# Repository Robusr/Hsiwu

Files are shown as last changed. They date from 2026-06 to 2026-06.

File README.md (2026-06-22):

<p align="center">
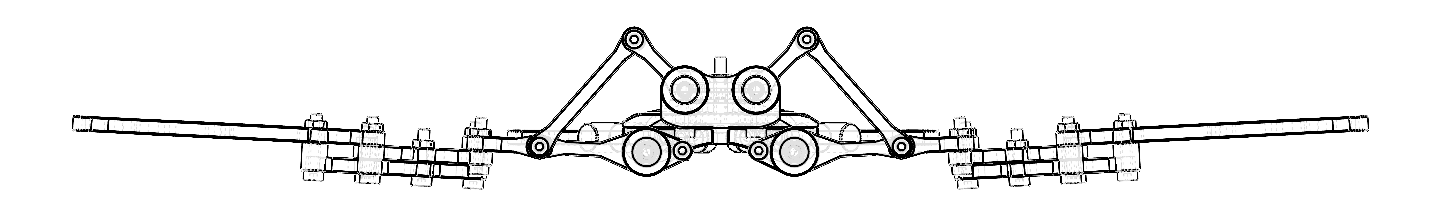
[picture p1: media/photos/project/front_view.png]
Hsiwu - Biomimetic Bat Robot Front Elevation
  
</p>

<h1 align="center">Hsiwu</h1>

<p align="center">
  <strong>MCU-less Analog Biomimetic Bat Flapping-Wing Robot</strong>
  <br>
  Three-segment independently-driven wings with pure analog control
</p>

<p align="center">
  
  
  
  
  
  <br>
  <a href="./README.md">English</a> | <a href="./README.zh-CN.md">中文版本</a>
</p>

---

## Name Origin

<p align="center">
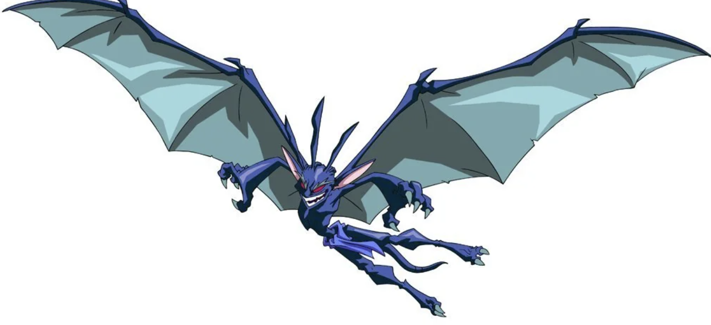
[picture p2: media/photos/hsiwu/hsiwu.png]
Hsi Wu — Sky Demon from Jackie Chan Adventures
  
  <br>
  <em><strong>Hsi Wu</strong> (西木 / Xī Mù), the Sky Demon of <strong>Jackie Chan Adventures</strong>.</em>
</p>

The project name **Hsiwu** is derived from **Hsi Wu** (西木), the bat-like **Sky Demon** from *Jackie Chan Adventures* (《成龙历险记》). A fitting namesake: just as Hsi Wu ruled the sky with his segmented, morphing wings, this robot replicates the segmented membrane deformation of a real bat in flight.

---

## About The Project

**Hsiwu** — named after the bat-like Sky Demon — is a biologically inspired bionic bat flapping-wing robot. Unlike conventional single-segment rigid-wing drones, it replicates the segmented membrane deformation of a real bat in flight. Each wing is divided into three independently driven segments — **leading edge**, **middle section**, and **trailing edge** — each powered by its own DC motor.

The bionic design takes the *Rhinolophus luctus* (great woolly horseshoe bat) as its morphological reference. Through a crank-rocker four-bar linkage mechanism, the continuous rotary motion of each DC motor is converted into the oscillating reciprocating swing that drives the wing segments—faithfully reproducing the coupled flapping-and-stretching kinematics of a real bat wing membrane.

A defining characteristic of this project is its **pure analog control architecture**. The system uses no microcontroller (MCU) and no embedded software whatsoever. Instead, it relies entirely on discrete analog and digital logic circuits — **NE555** timers, **74HC04** inverters, and **L293D** H-bridge drivers — to generate the synchronized periodic reciprocating motion that drives the wings.

The project spans a complete engineering stack: analog electronics design, digital logic, custom PCB layout, mechanical structure modeling (SolidWorks), FDM 3D printing, and hardware assembly and debugging.

> **Reference Paper**: The aerodynamic and mechanical principles are adapted from *"Design and Manufacture of Bionic Bat Aircraft"* (Qi Jinhao, Zhang Weiping, 2020), published in *Machine Design and Research*, Vol. 36, No. 5. The reference prototype achieves a 205 mm wingspan, 17.81 g total mass, 70° flapping angle, ~10 Hz flapping frequency, and ~0.16 N lift under a 3.7 V power supply.

<p align="center">
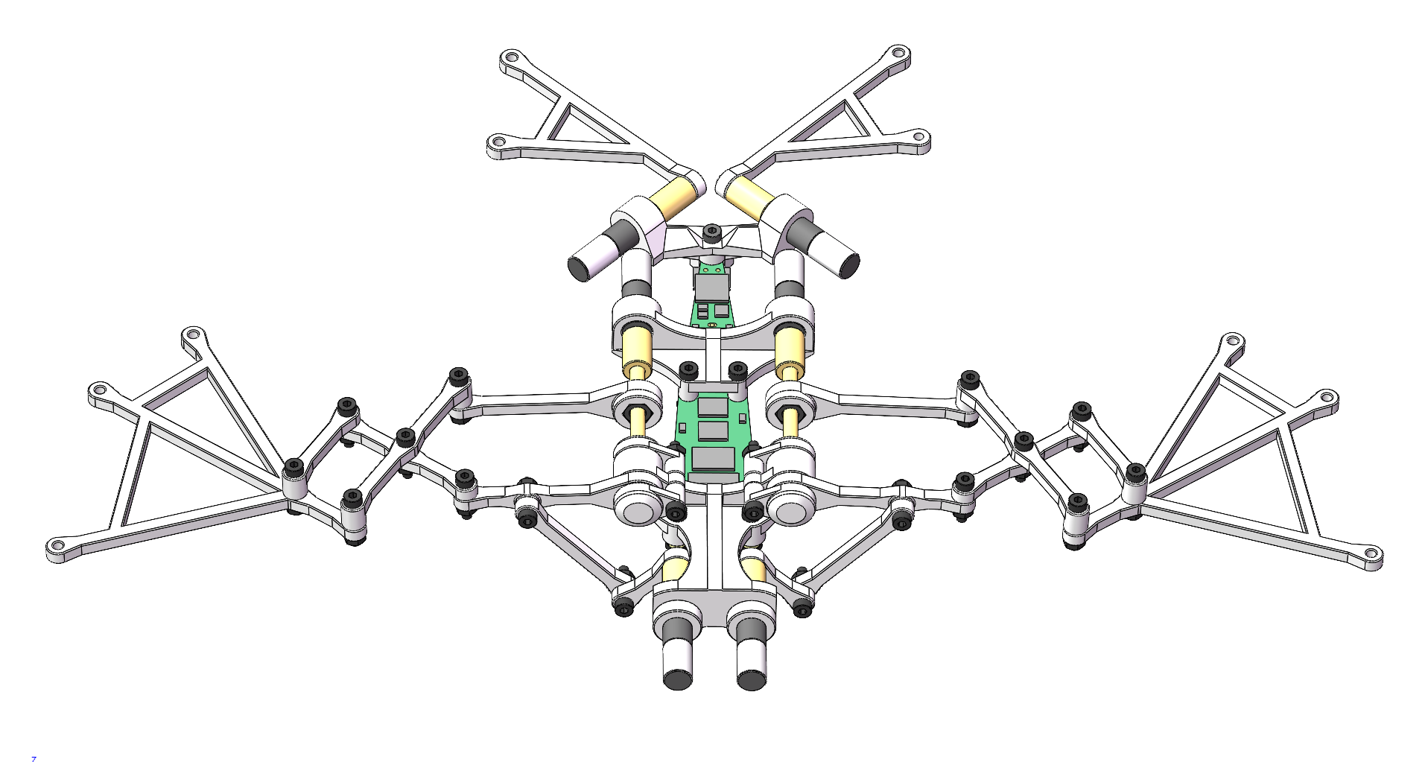
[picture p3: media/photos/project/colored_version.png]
Hsiwu Full Assembly Render
  
  <br>
  <em><strong>Figure 0 — Project Overview.</strong> Full-color 3D render of the complete Hsiwu assembly. The bilateral symmetric frame chassis (central support, head support, tail bracket), six independently-driven wing segments (three per side — leading, middle, trailing edges), linkage rods, lead-screw-driven scissor expansion mechanism, and custom-shaped PCB are all visible. This render corresponds to the final assembly state defined in <code>final_assembly.SLDASM</code>.</em>
</p>

---

## Key Features

- **Bio-inspired Wing Kinematics** — Three independently-driven segments per wing (Leading, Middle, Trailing), each with its own DC motor, mimicking the stretching and bending of a real bat's wing membrane. The crank-rocker four-bar linkage converts continuous motor rotation into oscillatory flapping.
- **Zero MCU / Zero Code** — Pure analog control: NE555 astable multivibrators for timing, 74HC04 hex inverters for phase splitting, and L293D dual H-bridges for bidirectional motor drive. No microcontroller, no firmware, no programming required.
- **Custom Shaped PCB** — A specialized irregularly-shaped PCB designed in EasyEDA (LCEDA) and Altium Designer, contour-fit to the internal mechanical frame. Integrates power management, signal generation, and motor driving onto a single compact board.
- **Modular Mechanical Design** — Fully parameterized 3D models built in SolidWorks. Frame components are FDM 3D-printable, assembled with standard M2/M3 screws and hinge linkages for easy tuning and repair.
- **Integrated Power Management** — Single-cell 3.7V LiPo battery input with MT3608 boost converter (3.7V → 7.35V for motors), on-board LDO regulation (5V for logic), reverse-polarity protection, and power switch with indicator LED.

---

## System Architecture

### 1. Electronics System (`/electronics`)

The core logic is distributed across five functional blocks integrated onto a single custom PCB:

<p align="center">
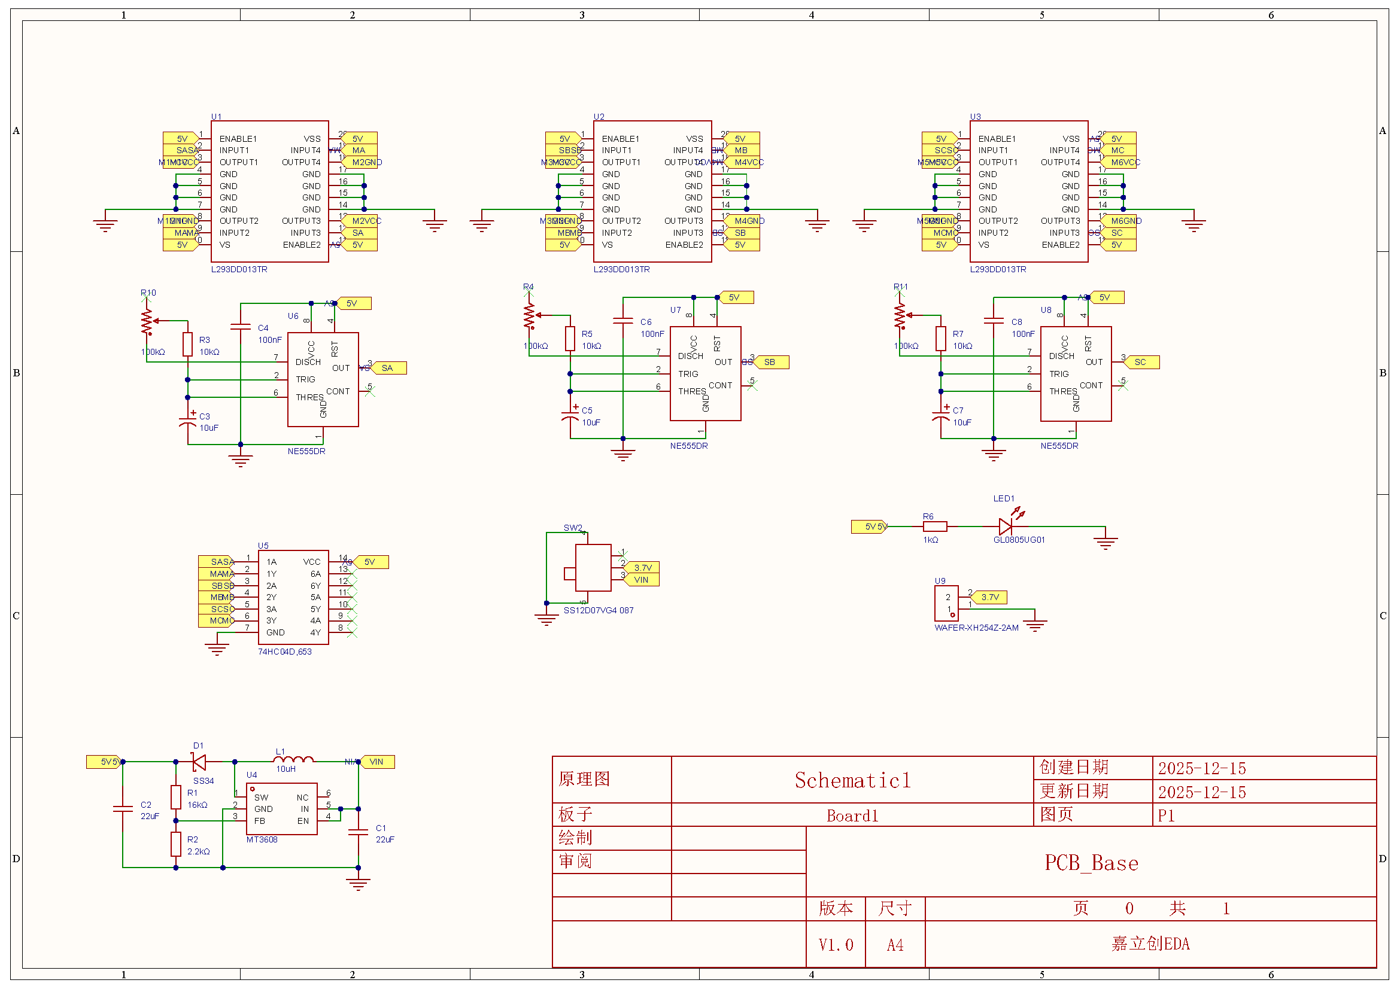
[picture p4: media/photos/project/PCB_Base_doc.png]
Full System Schematic
  
  <br>
  <em><strong>Figure 1 — Full System Schematic.</strong> Complete circuit diagram showing four functional blocks: (left) MT3608 boost converter with Schottky diode reverse-polarity protection and power switch; (upper-middle) three NE555 astable multivibrator stages generating independent ~4.8 Hz square-wave timing signals; (right) 74HC04 hex inverter for complementary phase generation; (lower) three L293D dual H-bridge drivers, each using one half-bridge channel per motor to produce continuous forward/reverse reciprocation.</em>
</p>

| Block | Components | Function |
|---|---|---|
| **Power Supply** | MT3608, LDO, Schottky diode | 3.7V LiPo → 7.35V (boost, motors) + 5V (LDO, logic). Reverse-polarity protection, on/off switch with indicator LED. |
| **Timing Generation** | 3× NE555 (astable) | Three independent, synchronized square-wave oscillators at ~4.8 Hz. Sets the flapping frequency. Each NE555's RC network can be independently tuned for per-segment timing adjustment. |
| **Phase Inversion** | 1× 74HC04 hex inverter | Inverts the three NE555 outputs to produce complementary logic levels for H-bridge direction control. Each NE555 output drives one inverter channel, yielding the inverted signal for the opposing half-bridge. |
| **Motor Drive** | 3× L293D dual H-bridge | Each L293D uses one half-bridge channel per motor. Complementary logic signals produce continuous forward/reverse reciprocation. Built-in flyback diodes protect against inductive kickback. |
| **PCB Layout** | Custom contour | Vertical modular layout; board outline shaped to fit the internal mechanical frame. Irregular board profile matches the central support chassis curvature. |

<p align="center">
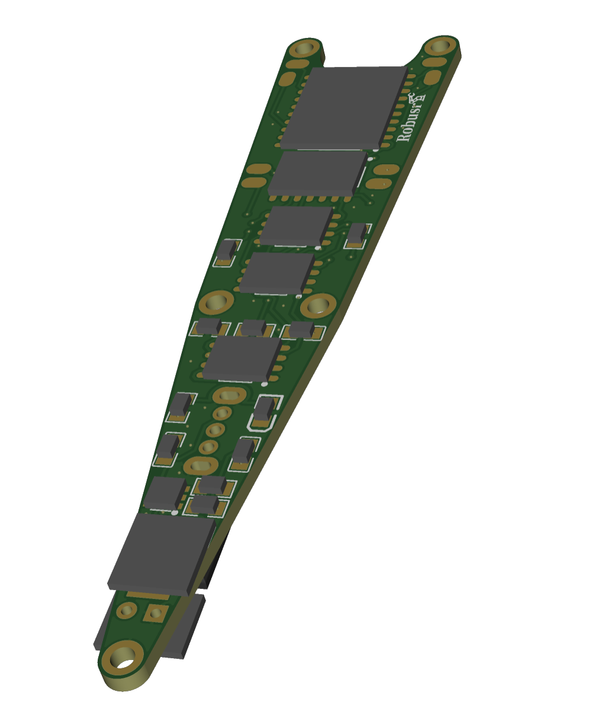
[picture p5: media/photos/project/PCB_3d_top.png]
3D PCB Render
  
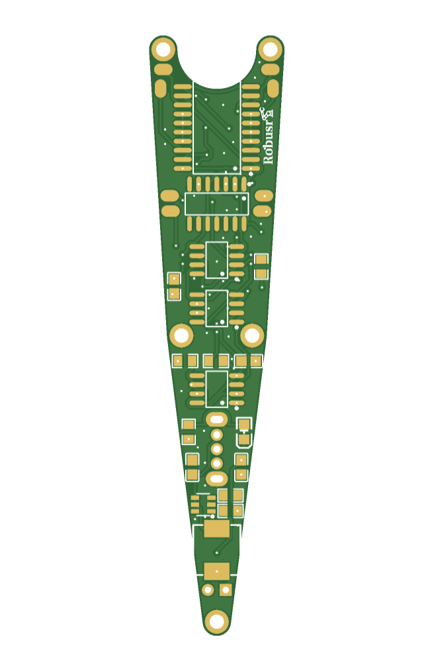
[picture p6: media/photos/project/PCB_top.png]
2D Top Layer
  
  <br>
  <em><strong>Figure 2a–2b — PCB Design Views (I).</strong> Left: 3D render showing component placement on the custom-shaped PCB — three NE555 (SOP-20, U1–U3), 74HC04 (SOIC-14, U5), three L293D (SOIC-8, U6–U8), MT3608 (SOT-23-6, U4), SMC Schottky diode (D1), SMD inductor (L1), XH-2A connectors (U9), 0805 passive components (R1–R11, C1–C8), and slide switch (SW2). Right: 2D top-layer copper routing with silkscreen overlay.</em>
</p>

<p align="center">
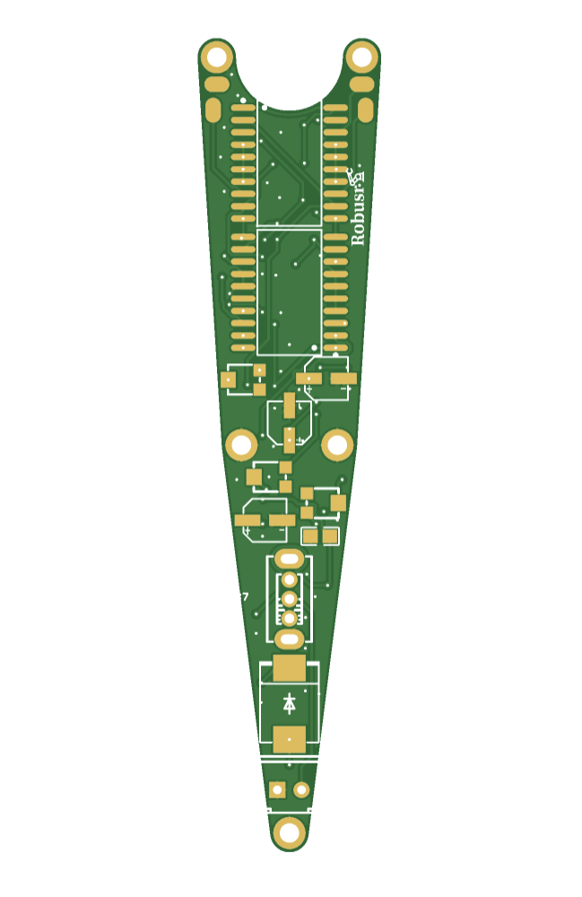
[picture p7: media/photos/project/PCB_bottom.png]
2D Bottom Layer
  
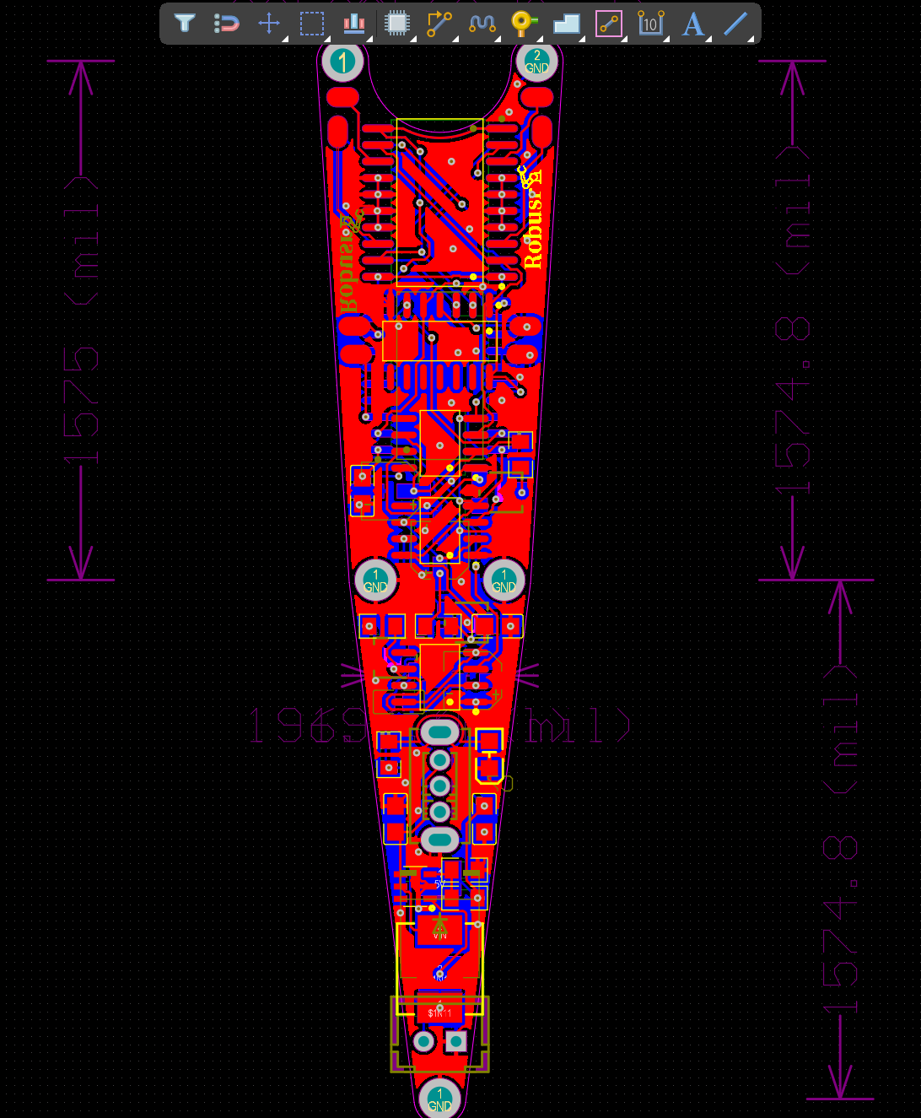
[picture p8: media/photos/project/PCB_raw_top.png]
Raw Top Routing
  
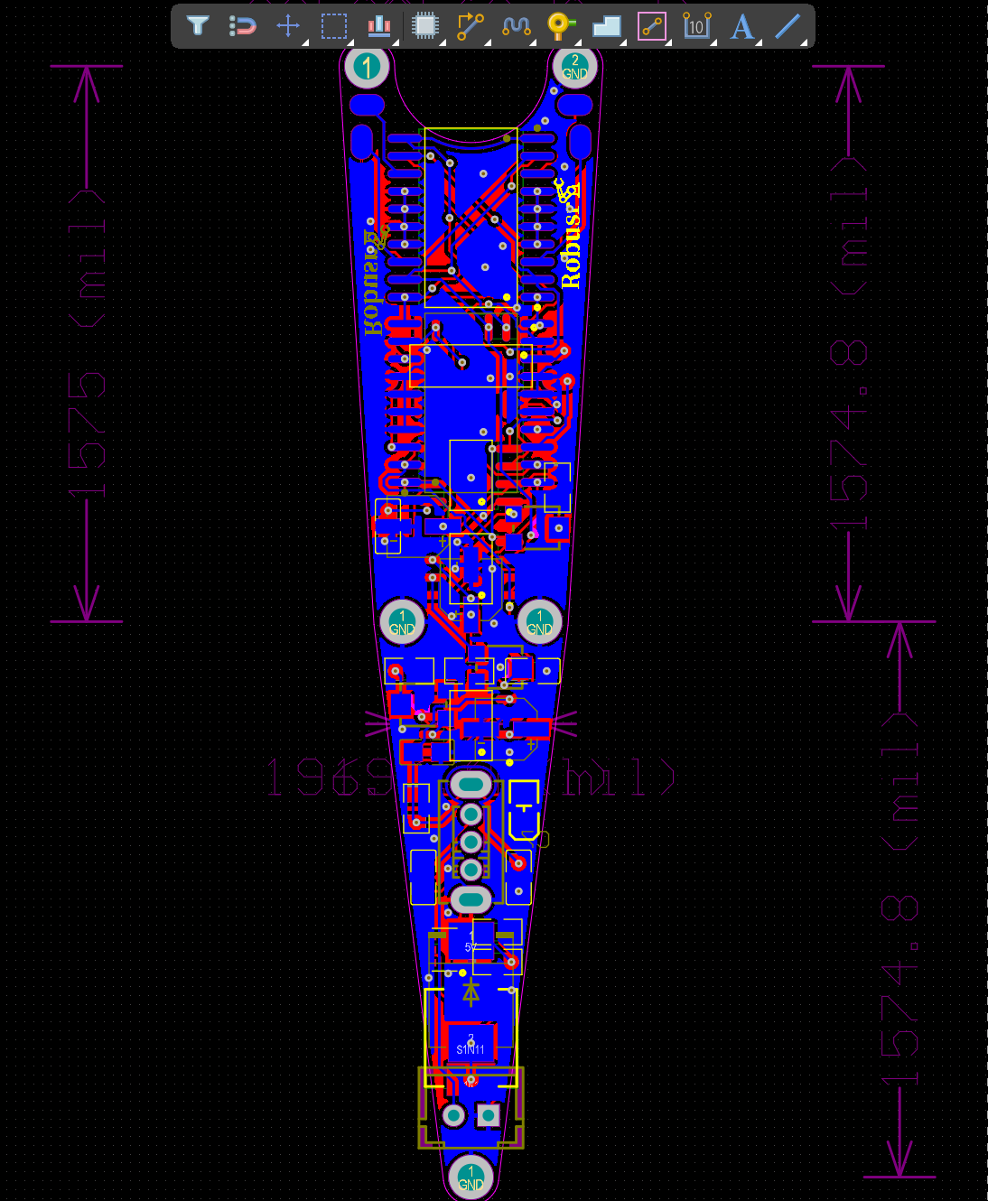
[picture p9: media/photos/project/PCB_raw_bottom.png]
Raw Bottom Routing
  
  <br>
  <em><strong>Figure 2c–2e — PCB Design Views (II).</strong> Left to right: Bottom copper layer with silkscreen; raw top-layer routing trace (no fill); raw bottom-layer routing trace (no fill). The Gerber fabrication files are available in <code>electronics/output/gerber/</code>.</em>
</p>

### 2. Mechanical Structure (`/mechanical`)

The mechanical assembly is designed in SolidWorks (`.SLDPRT` / `.SLDASM` source files) and manufactured via FDM 3D printing. The kinematic principles are adapted from the reference paper *"Design and Manufacture of Bionic Bat Aircraft"* (Qi & Zhang, 2020).

#### 2.1 Kinematic Mechanisms (Reference Paper)

The following kinematic schematics are reproduced from the reference paper. They illustrate the four core mechanisms that underlie the wing drive train:

<p align="center">
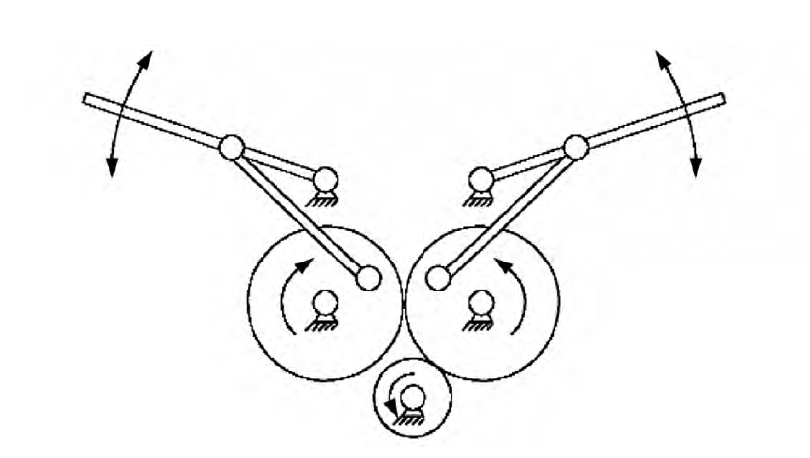
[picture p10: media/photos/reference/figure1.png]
Crank-Rocker Mechanism
  
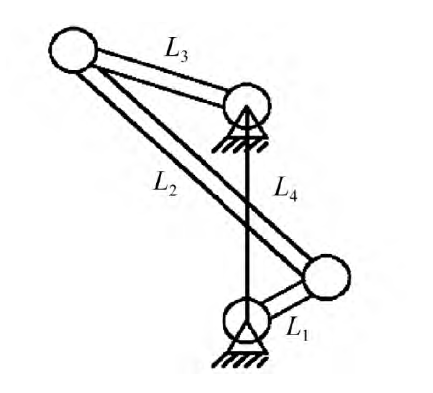
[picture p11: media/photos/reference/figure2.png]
Linkage Dimensions
  
  <br>
  <em><strong>Figure 3a–3b — Crank-Rocker Four-Bar Linkage.</strong> Left: Kinematic diagram of the crank-rocker mechanism that converts the motor shaft's continuous rotary motion into the rocker arm's oscillating up/down swing. The crank (driven by the geared hollow-cup DC motor) rotates continuously; the connecting rod transmits motion to the rocker, whose output angle determines the wing segment's flapping amplitude (~70° in the reference design). Right: Dimensioned linkage drawing with parameter table — key link lengths a/b/c/d/e/f/g/h/i/j/k and crank/rocker pivot angles α/β are dimensioned for the target 75° flapping stroke. The reference prototype uses linkage ratios optimized for a 205 mm wingspan.</em>
</p>

<p align="center">
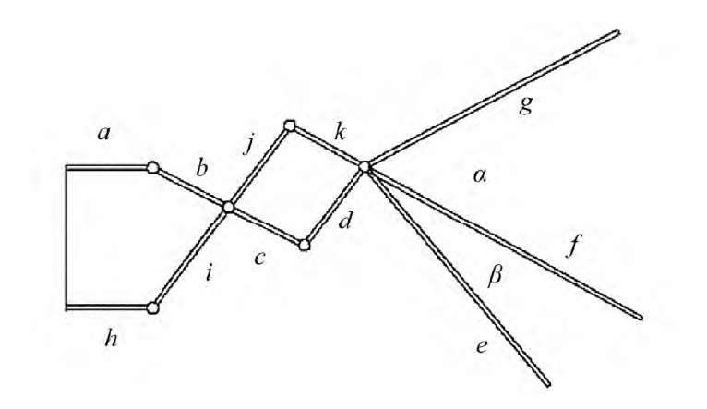
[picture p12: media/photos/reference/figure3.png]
Scissor Mechanism
  
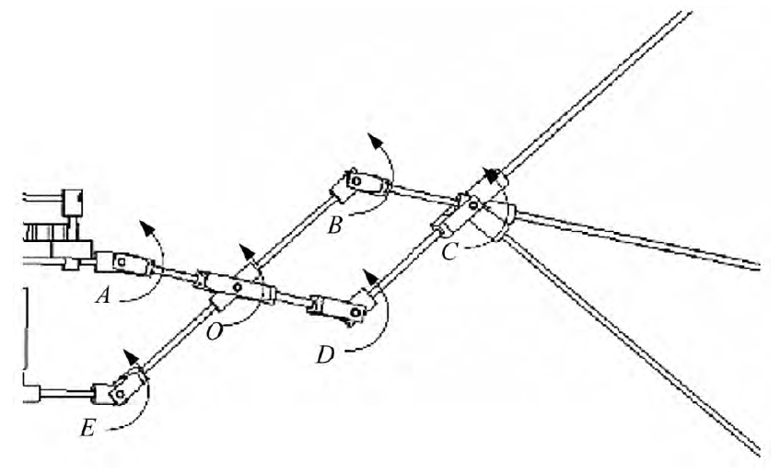
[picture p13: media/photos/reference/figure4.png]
Leg Mechanism
  
  <br>
  <em><strong>Figure 3c–3d — Scissor Expansion & Leg Drive Mechanism.</strong> Left: Scissor mechanism controlled by a lead screw (P = 0.4 mm pitch, d₂ = 1.74 mm effective diameter). The motor-driven lead screw advances/retracts a traveling nut, which pushes/pulls a scissor linkage to control wing membrane expansion and contraction. The reference paper calculates a lead screw driving torque M = 0.0064 N·mm. Right: Leg/transmission mechanism showing the motor-to-linkage coupling geometry, with pivot points O–O′ and reaction forces F<sub>A</sub>, F<sub>B</sub> resolved through static equilibrium analysis. The overall mechanical advantage is designed to deliver ~0.16 N of lift from a 3.7 V supply.</em>
</p>

#### 2.2 Project Mechanical Assembly

The project's mechanical assembly consists of the following sub-assemblies (all SolidWorks source files in `mechanical/source/`):

| Sub-assembly | Path | Key Parts | Description |
|---|---|---|---|
| **Structural Frame** | `structural/` | `central_support`, `head_support`, `tail_bracket` | Left-right symmetric chassis; the central support forms the main body, with head/tail brackets anchoring the wing pivot points |
| **Rod Linkages** | `rods/` | `rod_a`, `rod_bc`, `rod_d`, `rod_h`, `rod_ij`, `rod_kf` | Six linkage rod types forming the four-bar crank-rocker kinematic chains for each wing segment |
| **Motor & Coupling** | `motor/` | `four-stage_geared_hollow_cup_motor`, `2-to-3_coupling` | Hollow-cup DC motor with 4-stage planetary gear reduction; 2-to-3 shaft coupler for connecting to the lead screw |
| **Lead Screw Assembly** | `structural/` | `lead_screw`, `head_drive_shaft`, `bearing`, `center_bearing_cap`, `head_bearing_cover` | Lead screw (P = 0.4 mm) drives the scissor expansion linkage; supported by miniature bearings at both ends |
| **Pivot Hardware** | `structural/` | `head_pin`, `tail_pin` | Precision hinge pins for wing segment articulation at the leading and trailing pivot points |
| **Fasteners** | `fasteners/` | `SCA_M2_L10/L12/L14/L18`, `SLMNA-M2`, `SLMNA-M3` | M2 countersunk screws (10–18 mm lengths), M2/M3 lock nuts for frame assembly |
| **Final Assembly** | `assembly/` | `final_assembly.SLDASM` | Master assembly file referencing all sub-components in their assembled positions |

<p align="center">
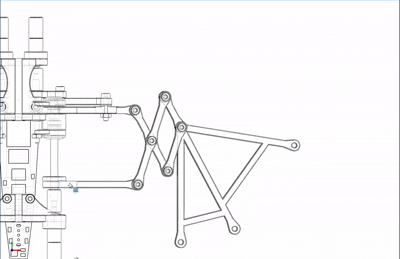
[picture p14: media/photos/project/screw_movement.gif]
Lead Screw Animation
  
  <br>
  <em><strong>Figure 4 — Lead Screw Transmission Animation.</strong> Dynamic demonstration of the lead-screw-driven scissor mechanism. As the motor rotates the lead screw, the traveling nut advances linearly, pushing the scissor linkage open to expand the wing membrane area — or retracting to contract it. This coupled expansion/flapping motion is a key biomimetic feature that replicates the bat wing's variable-camber aerodynamics.</em>
</p>

<p align="center">
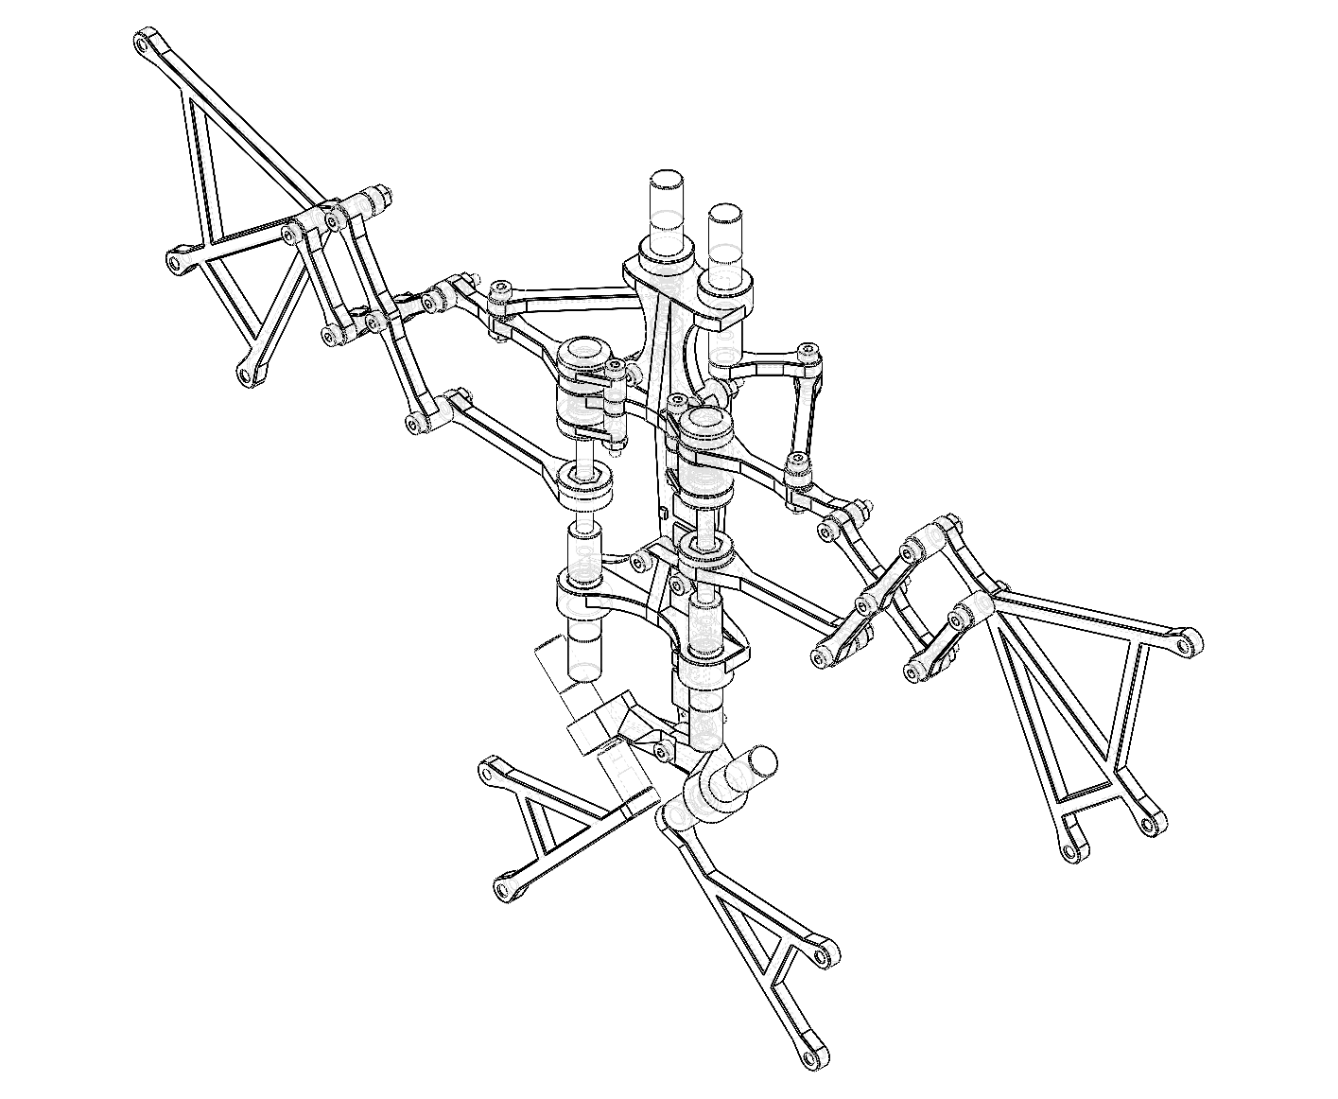
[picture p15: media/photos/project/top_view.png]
Top View
  
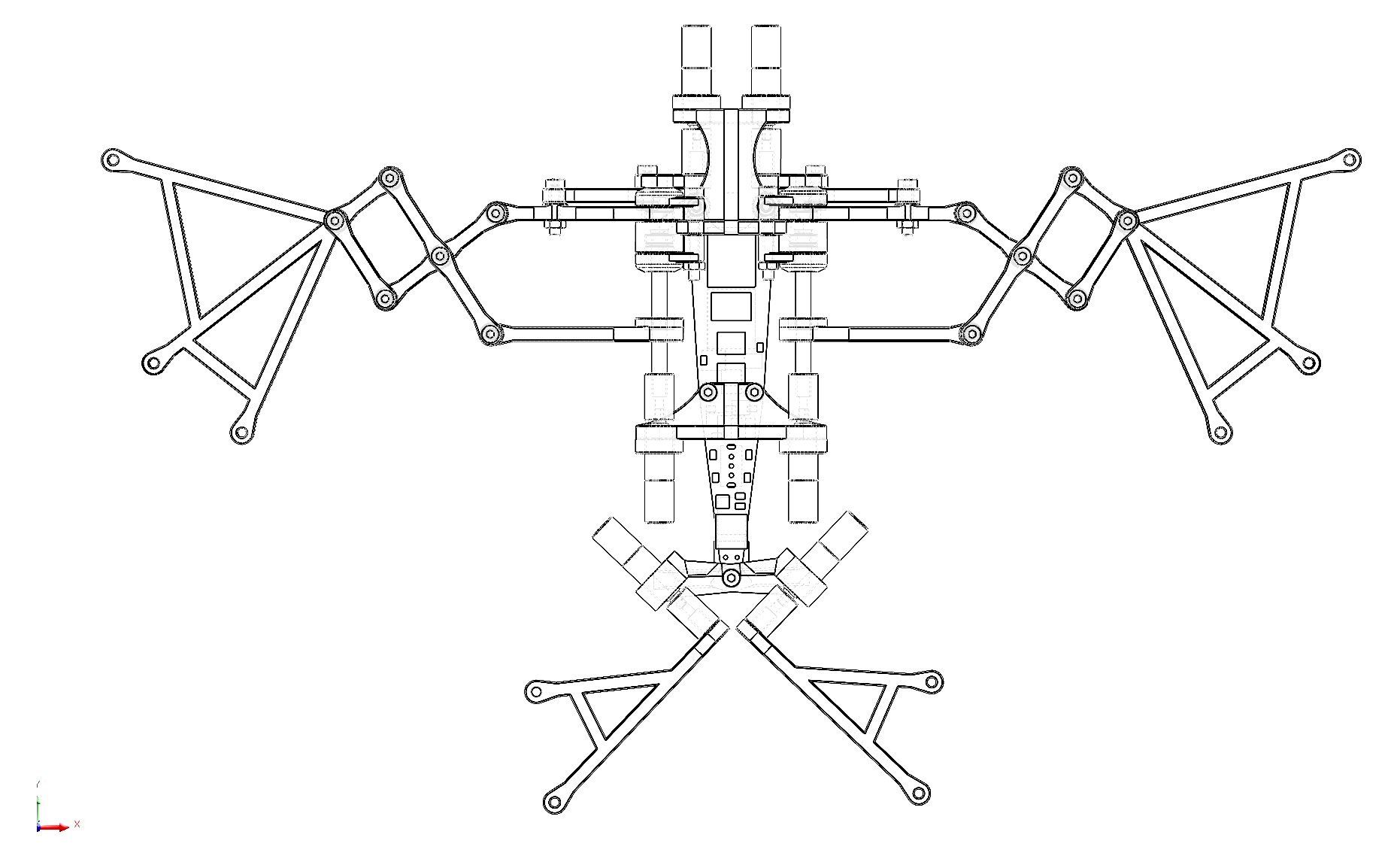
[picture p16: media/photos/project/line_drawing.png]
Isometric Wireframe
  
  <br>
  <em><strong>Figure 5a–5b — Mechanical Drawings.</strong> Left: Top/plan view — reveals the motor placement, linkage rod routing, and overall wingspan geometry. Right: Isometric wireframe view — a line-drawing render showing the complete kinematic skeleton with all linkage pivot points, rod connections, and structural frame members visible in a single perspective. The front elevation view is shown in the project banner above.</em>
</p>

---

## Repository Structure

```
HSIWU/
├── electronics/                 # PCB design files
│   ├── source/                  #   LCEDA project (.eprj2) + Altium Designer source files (.schdoc, .pcbdoc)
│   └── output/                  #   Gerber files, BOM, pick-and-place (.csv/.xlsx), PDF schematic
├── mechanical/                  # 3D CAD models (SolidWorks)
│   ├── source/                  #   Native SLDPRT/SLDASM files
│   │   ├── structural/          #     Frame, lead screw, bearings, pins, brackets
│   │   ├── rods/                #     Six linkage rod types (a, bc, d, h, ij, kf)
│   │   ├── motor/               #     Geared hollow-cup motor + shaft coupler
│   │   ├── fasteners/           #     M2/M3 screws & lock nuts
│   │   ├── pcb_3d_models/       #     PCB with all component 3D models placed
│   │   └── assembly/            #     Master assembly file
│   └── output/                  #   Export files — STEP (3D printing), STL (laser cutting)
├── docs/                        # Technical documentation
│   ├── en/                      #   English docs — theory of operation, mechanical design, assembly guide
│   └── zh-CN/                   #   中文文档 — 工作原理、机械设计、组装指南
├── BOM/                         # Bill of Materials spreadsheet (.xlsx)
├── media/                       # Project media assets
│   ├── photos/
│   │   ├── project/             #   Renders, PCB views, mechanical drawings, test photos
│   │   └── reference/           #   Reference paper figures and the original paper (PDF)
│   └── videos/                  #   Demonstration videos (.mp4)
├── .github/                     # GitHub community files
│   ├── CODEOWNERS               #   Code ownership definitions
│   ├── PULL_REQUEST_TEMPLATE.md #   PR template
│   ├── ISSUE_TEMPLATE/          #   Bug report & feature request templates
│   └── FUNDING.yml              #   Funding/sponsor configuration
├── .gitignore                   # CAD/EDA/3D-printing-aware ignore rules
├── .gitattributes               # Binary/text handling & diff configuration
├── CHANGELOG.md                 # Version history (Keep a Changelog format)
├── CONTRIBUTING.md              # Contributor guidelines (English)
├── CONTRIBUTING.zh-CN.md        #   中文贡献者指南
├── LICENSE.md                   # MIT License
├── README.md                    # Project overview (English)
└── README.zh-CN.md              # 项目概览（中文）
```

---

## Bill of Materials

See [`BOM/`](BOM/) for the complete component spreadsheet. Key components:

| Category | Item | Qty | Notes |
|---|---|-----|---|
| **Frame** | 3D-printed parts (ABS/PLA) | — | Central support, head support, tail bracket, bearing caps; 0.2 mm layer height recommended |
| **Fasteners** | M2 countersunk screws (10/12/14/18 mm) | — | SCA series |
| | M2/M3 lock nuts | — | SLMNA series |
| **Bearings** | Miniature ball bearings | — | For lead screw and pivot joints |
| **Motors** | DC hollow-cup geared motors | 3 | Four-stage planetary gear reduction; one per wing segment |
| **Power** | 3.7V LiPo battery | 1 | Single-cell |
| **ICs** | NE555 timer (SOIC-8 equiv., on SOP-20 carrier) | 3 | Astable multivibrator configuration |
| | 74HC04 hex inverter (SOIC-14) | 1 | Six NOT gates; three used for phase inversion |
| | L293D dual H-bridge driver (SOIC-8 equiv.) | 3 | One half-bridge channel per motor |
| | MT3608 boost converter (SOT-23-6) | 1 | 3.7V → 7.35V step-up |
| **Passives** | Resistors, capacitors (0805) | — | Timing RC networks, decoupling, filter |
| | Schottky diode (SMC) | 1 | Reverse-polarity protection |
| | Power inductor (SMD, 7.3×6.8 mm) | 1 | MT3608 boost inductor |
| | Adjustable resistors (SMD trimmer) | 3 | Per-segment frequency fine-tuning |
| **Connectors** | XH-2A 2-pin header (P2.50) | — | Motor wire connections |
| | Slide switch (SS12D07VG4) | 1 | Power on/off |
| | Indicator LED (0805) | 1 | Green power-on indicator |

---

## How to Replicate

### 1. Electronics
Open [`electronics/`](electronics/). The schematic is documented in `PCB_Base.pdf` and `PCB_Base_doc.png` (see **Figure 1**). The board can be manufactured directly from the Gerber files in `electronics/output/gerber/`, or you can re-export from the EasyEDA (LCEDA) project in `electronics/source/JLC/`. The pick-and-place file (`electronics/output/pick_and_place/PCB_BASE.csv`) and BOM (`electronics/output/bom/PCB_Base_BOM.xlsx`) are ready for SMT assembly services.

### 2. Mechanical
Find the 3D models in [`mechanical/`](mechanical/). Export the parts to STL and print them on a standard FDM 3D printer (0.2 mm layer height recommended; ABS for structural durability or PLA for ease of printing). The STEP files in `mechanical/output/3dp/` are ready for direct slicing and printing. For laser-cut parts (rods), use the STL files in `mechanical/output/laser/`. To modify the design, open the native SolidWorks source files in `mechanical/source/` — all parts are fully parameterized.

### 3. Assembly
1. Solder all components onto the custom PCB according to the schematic (**Figure 1**). Refer to the PCB layout views (**Figure 2a–2e**) for component placement.
2. Connect the three motor wires to the XH-2A headers on the PCB.
3. 3D-print the structural frame parts: `central_support`, `head_support`, `tail_bracket`, `head_bearing_cover`, `center_bearing_cap`, `head_drive_shaft`, `head_pin`, `tail_pin`.
4. 3D-print or laser-cut the linkage rods: `rod_a`, `rod_bc`, `rod_d`, `rod_h`, `rod_ij`, `rod_kf`.
5. Assemble the frame using M2/M3 screws, lock nuts, and miniature bearings as specified in `final_assembly.SLDASM`. Refer to the mechanical drawings (**Figure 5a–5b**) and the front elevation banner for assembly reference.
6. Mount the PCB onto the central support chassis.

### 4. Power Up
Insert the 3.7V LiPo battery and flip the power switch (SW2). The onboard green LED (LED1) should illuminate, and the wings should begin flapping at the designed ~4.8 Hz frequency. The flapping rate can be fine-tuned by adjusting the three trimmer resistors (R4, R10, R11) that set each NE555's RC time constant.

---

## Demo & Testing

During the powered-on test, the onboard green indicator LED illuminates and the 3D-printed robot executes the full flapping motion. A Tektronix TDS1001B-SC oscilloscope is used to monitor the ~4.8 Hz square-wave output from the NE555 oscillator stages and verify signal integrity.

<p align="center">
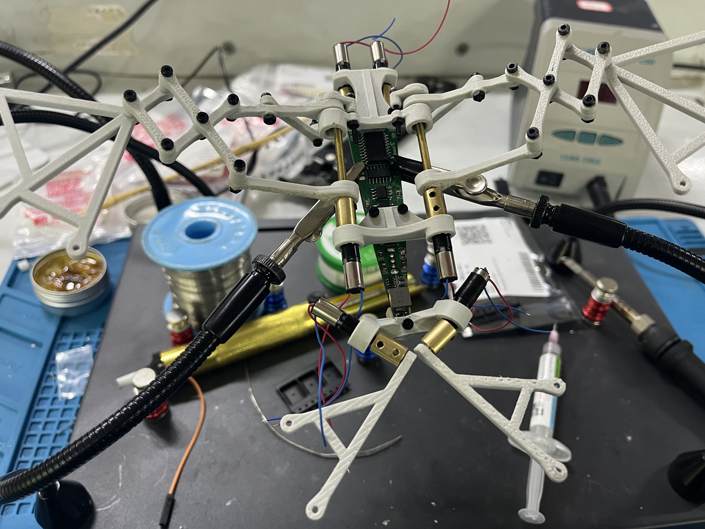
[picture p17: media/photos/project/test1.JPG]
Assembly Setup
  
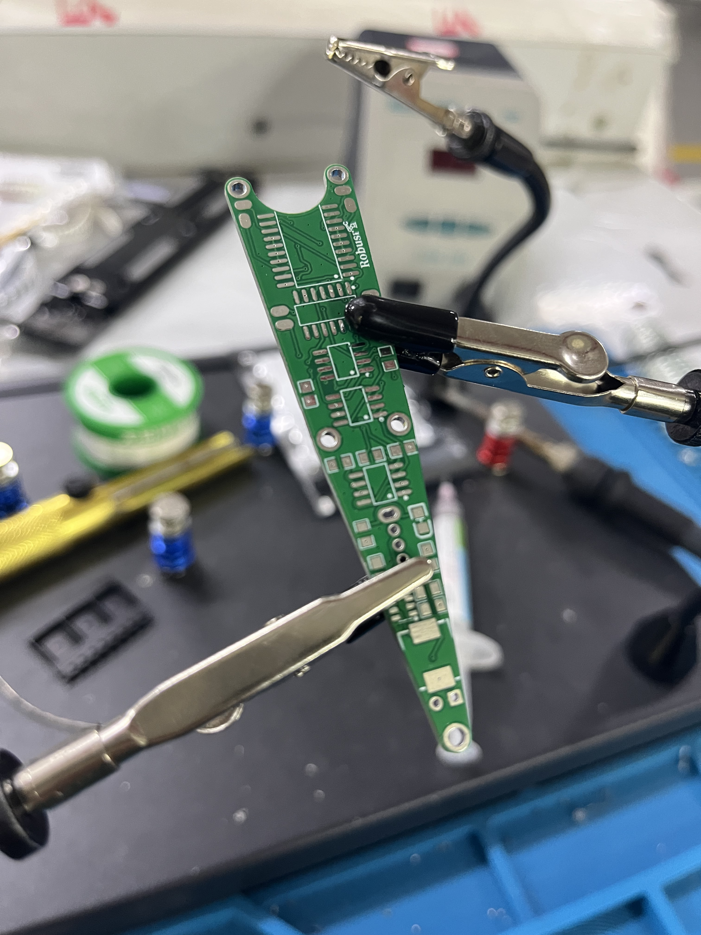
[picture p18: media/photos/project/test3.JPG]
PCB Soldering Setup
  
  <br>
  <em><strong>Figure 6a–6b — Assembly & Fabrication.</strong> Left: Bench assembly setup — third-hand tool with magnifying glass holding the partially assembled mechanical frame; PCB, motors, and linkage rods visible on the work mat. Right: PCB soldering station — the custom-shaped board undergoing manual SMT soldering of 0805 passives and ICs.</em>
</p>

<p align="center">
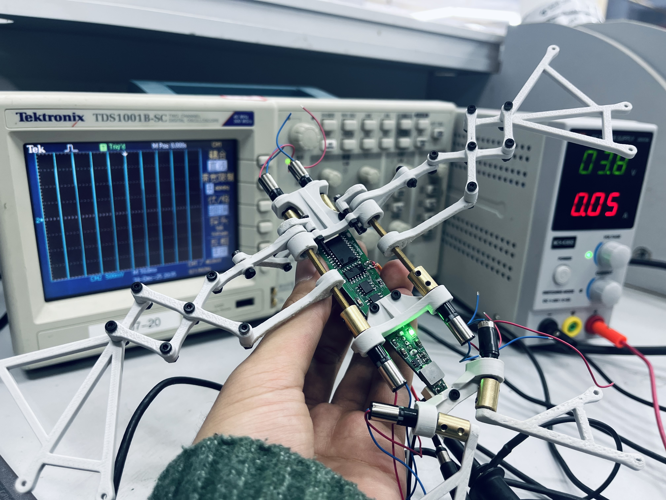
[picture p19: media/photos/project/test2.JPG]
Live Oscilloscope Test
  
  <br>
  <em><strong>Figure 7 — Live Oscilloscope Test.</strong> Tektronix TDS1001B-SC digital storage oscilloscope probing the NE555 output waveform during a powered-on test. The scope displays the ~4.8 Hz square wave (period ≈ 208 ms) with voltage swing from 0 V to V<sub>CC</sub> (5 V logic rail), confirming correct astable multivibrator operation. Multiple channels allow simultaneous monitoring of all three motor drive signals for phase verification.</em>
</p>

---

## Design Specifications

| Parameter | Value | Source |
|---|---|---|
| **Bionic Reference** | *Rhinolophus luctus* (great woolly horseshoe bat) | Reference paper |
| **Wingspan** | 205 mm (reference) | Qi & Zhang, 2020 |
| **Total Mass** | 17.81 g (reference) | Qi & Zhang, 2020 |
| **Flapping Frequency** | ~4.8 Hz (this project) / ~10 Hz (reference) | NE555 RC network / paper |
| **Flapping Angle** | ~70° (reference target) | Crank-rocker geometry |
| **Power Supply** | 3.7V LiPo single-cell | This project |
| **Motor Supply** | 7.35V (boosted) | MT3608 converter |
| **Logic Supply** | 5V (regulated) | On-board LDO |
| **Motor Type** | Hollow-cup DC, 4-stage planetary geared | ZWPD006006-26 (reference) |
| **Lead Screw Pitch** | P = 0.4 mm, d₂ = 1.74 mm | Reference paper |
| **Gear Ratio** | 1:4 (motor output : lead screw) | Reference paper |
| **PCB Design Tools** | EasyEDA (LCEDA) + Altium Designer | This project |
| **CAD Software** | SolidWorks (native .SLDPRT/.SLDASM) | This project |
| **Manufacturing** | FDM 3D printing (frame) + FR-4 PCB | This project |

---

## License

Distributed under the [MIT License](LICENSE.md).

---

## Acknowledgments

- **Reference Work** — *"Design and Manufacture of Bionic Bat Aircraft"* (Qi Jinhao, Zhang Weiping, 2020), published in *Machine Design and Research* (Vol. 36, No. 5, pp. 38–43), Shanghai Jiao Tong University. This paper provides the theoretical foundation for bat flight kinematics, four-bar linkage design, scissor mechanism force analysis, and prototype validation methodology upon which this project's mechanical design is based.
- **Name Inspiration** — The character **Hsi Wu** (西木, the Sky Demon) from the animated series *Jackie Chan Adventures* (《成龙历险记》), whose iconic bat-like form inspired the project's name and its tribute to segmented-wing biomechanics.
- **Tools** — SolidWorks (mechanical CAD), EasyEDA / LCEDA (PCB design), Altium Designer (schematic capture), Tektronix TDS1001B-SC (test & measurement).
- **Inspiration** — FESTO BionicOpter and Bat Bot B2 (Caltech/UIUC) for demonstrating the feasibility of bio-inspired bat flight; the broader bat flight biomechanics literature (Swartz et al., Tian et al., Wolf et al.) for wing membrane mechanics and flapping kinematics research.

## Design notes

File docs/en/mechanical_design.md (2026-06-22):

# Mechanical Design — Hsiwu

## Design Philosophy

The Hsiwu mechanical structure is designed around three principles:

1. **Biomimetic fidelity** — the segmented wing kinematics must faithfully
   reproduce the coupled flapping-and-stretching motion of a real bat wing
   membrane (*Rhinolophus luctus* as the morphological reference).
2. **Manufacturability** — all structural components are FDM 3D-printable
   without supports on a standard consumer printer.
3. **Modularity** — sub-assemblies are independent; a damaged wing segment or
   linkage can be replaced without reprinting the entire robot.

## Kinematic Foundation

### Crank-Rocker Four-Bar Linkage

The core mechanism that converts continuous motor rotation into oscillating
wing flapping is the **crank-rocker four-bar linkage** (Grashof type: crank-rocker).

```
                         connecting rod (rod_bc)
                    ┌─────────────────────────────┐
                    │                             │
    crank (rod_a) ──┤                             ├── rocker (rod_d)
    (fixed to motor │                             │   (output to wing
     shaft, rotates │                             │    segment)
     360° CW)       │                             │
                    │      ground link (frame)     │
                    └─────────────────────────────┘
```

**Grashof condition:** For a crank-rocker to exist, the sum of the shortest
and longest links must be less than the sum of the remaining two links:
```
s + l < p + q
```
where s = shortest link, l = longest link, and p, q are the other two.

In the Hsiwu linkage:
- **Crank** (rod_a) = shortest link — driven by motor, rotates continuously
- **Coupler** (rod_bc) = intermediate — transmits motion to rocker
- **Rocker** (rod_d) = output — oscillates through ~70°
- **Ground** = the mechanical frame (distance between motor shaft and rocker pivot)

### Flapping Angle

The rocker angular range (flapping angle) is determined by the linkage
geometry:
```
θ_max = arcsin((r_crank + r_coupler) / r_rocker)  [approximate upper bound]
θ_min = arcsin((r_crank - r_coupler) / r_rocker)  [approximate lower bound]
Flapping amplitude = θ_max − θ_min ≈ 70°
```

### Six Linkage Rod Types

Each wing segment (3 per side) uses its own set of linkages. All three share
the same kinematic topology but may differ slightly in dimensions to account
for the wing's tapered planform.

| Rod | Role | Notes |
|-----|---|---|
| `rod_a` | Crank | Attaches to motor output shaft; shortest link |
| `rod_bc` | Coupler | Connects crank to rocker; the BC designation indicates two variants sharing a common geometry |
| `rod_d` | Rocker | Output link; drives the wing segment |
| `rod_h` | Auxiliary link | Connects to the lead screw driven nut |
| `rod_ij` | Scissor link | Part of the scissor expansion mechanism |
| `rod_kf` | Tie link | Structural connector between wing segments |

## Lead Screw & Scissor Mechanism

### Purpose

In a real bat, the wing membrane not only flaps but **stretches** — the
cambers changes dynamically across the wing cycle. Hsiwu replicates this
with a **lead screw-driven scissor linkage** that expands and contracts
the effective wing area in coordination with the flapping motion.

### Mechanism

```
   motor → 2-to-3 coupling → lead screw (rotates)
                                      │
                 traveling nut (translates linearly)
                                      │
                           scissor linkage (expands/contracts)
                                      │
                         wing membrane area changes
```

### Lead Screw Specifications

| Parameter | Value |
|---|---|
| Pitch (P) | 0.4 mm |
| Effective diameter (d₂) | 1.74 mm |
| Driving torque (M) | 0.0064 N·mm (calculated) |
| Gear ratio (motor : screw) | 1:4 |

### Torque Calculation

From the reference paper (Qi & Zhang, 2020), the lead screw driving torque is:
```
M = F × d₂/2 × tan(α + ρ)
```
where:
- F = axial load on the nut
- d₂ = effective diameter
- α = lead angle = arctan(P / (π·d₂))
- ρ = friction angle = arctan(μ)

With P = 0.4 mm, d₂ = 1.74 mm, μ ≈ 0.1 (steel-on-plastic):
```
α = arctan(0.4 / (π × 1.74)) ≈ 4.2°
ρ = arctan(0.1) ≈ 5.7°
M = 0.0064 N·mm
```

### Force Analysis

The scissor mechanism trades displacement for force. As the nut advances by
Δx, the scissor tips move laterally by Δy. The mechanical advantage is:
```
MA = F_y / F_x ≈ cot(β) / 2
```
where β is the scissor half-angle. As the scissor opens (β → small), MA is
high; as it nears full extension (β → large), MA decreases.

## Structural Frame

### Central Support (`central_support`)

The main chassis. Features:
- Motor mounting bosses (three per side)
- Bearing seats for the lead screw
- PCB mounting standoffs (contour-matched)
- M2/M3 clearance holes for frame assembly
- Weight-reduction cutouts

### Head & Tail Supports

- **Head support** — anchors the leading-edge wing pivot and the head bearing
  of the lead screw
- **Tail bracket** — anchors the trailing-edge pivot point

### Bearings & Pins

- **Bearings** — miniature ball bearings support the lead screw at both ends,
  housed in `center_bearing_cap` and `head_bearing_cover`
- **Head pin / Tail pin** — precision hinge pins for wing segment articulation

## Motor & Coupling

### Hollow-Cup DC Motor

The reference motor type is ZWPD006006-26, a hollow-cup (coreless) DC motor
with a 4-stage planetary gearbox.

**Hollow-cup motor advantages:**
- Lower rotor inertia → faster response to direction reversals
- No cogging torque → smooth operation at low speeds
- Higher efficiency → longer battery life

**4-stage planetary gearbox:**
- High reduction ratio in a compact form factor
- Coaxial input/output → simplifies mechanical layout
- Even torque distribution across planet gears → durability

### 2-to-3 Shaft Coupler

Connects the motor output shaft (2 mm diameter) to the lead screw input
(3 mm diameter). The coupler accommodates minor misalignment and transmits
torque via set screws.

## Assembly Structure

```
final_assembly.SLDASM
├── central_support.SLDPRT                 # Main chassis
├── head_support.SLDPRT                    # Forward frame member
├── tail_bracket.SLDPRT                    # Aft frame member
├── [Left Wing]
│   ├── rod_a.SLDPRT × 3                   # Cranks (one per segment)
│   ├── rod_bc.SLDPRT × 3                  # Couplers
│   ├── rod_d.SLDPRT × 3                   # Rockers
│   ├── rod_h.SLDPRT × 3                   # Auxiliary links
│   ├── rod_ij.SLDPRT × 3                  # Scissor links
│   ├── rod_kf.SLDPRT × 3                  # Tie links
│   └── motor.SLDASM × 3                   # Motor assemblies
├── [Right Wing — mirror of left]
├── lead_screw.SLDPRT                      # Lead screw shaft
├── head_drive_shaft.SLDPRT                # Drive shaft
├── bearing.SLDPRT × 2                     # Bearings
├── center_bearing_cap.SLDPRT              # Bearing retainer
├── head_bearing_cover.SLDPRT              # Bearing cover
├── head_pin.SLDPRT                        # Leading edge pivot
├── tail_pin.SLDPRT                        # Trailing edge pivot
└── [Fasteners]
    ├── SCA_M2_L10.SLDPRT                  # M2 × 10mm countersunk
    ├── SCA_M2_L12.SLDPRT                  # M2 × 12mm
    ├── SCA_M2_L14.SLDPRT                  # M2 × 14mm
    ├── SCA_M2_L18.SLDPRT                  # M2 × 18mm
    ├── SLMNA-M2.SLDPRT                    # M2 lock nut
    └── SLMNA-M3.SLDPRT                    # M3 lock nut
```

## Manufacturing Notes

### FDM 3D Printing

| Setting | Value |
|---|---|
| Layer height | 0.2 mm |
| Nozzle diameter | 0.4 mm |
| Infill | 20–30% (gyroid or grid) |
| Perimeters | 3 |
| Supports | None required |
| Material | ABS (durability) or PLA+ (ease) |

### Laser Cutting (Rods)

For rods, laser-cut acrylic or plywood can be used as an alternative to 3D
printing, providing better dimensional accuracy:
- 2–3 mm thick acrylic sheet
- STL files in `mechanical/output/laser/`
- Post-cut: debur edges, test-fit bearings

### Assembly Tips

1. **Bearings first** — press miniature bearings into their seats before
   assembling the frame
2. **Dry-fit** — assemble without screws first to verify all clearances
3. **Thread locking** — use a tiny drop of thread-locker (low-strength,
   e.g., Loctite 222) on motor mount screws
4. **Linkage alignment** — verify that all four-bar linkages move freely
   through their full range before connecting motors
5. **Wire routing** — run motor wires along the frame's internal channels
   to the PCB XH-2A connectors

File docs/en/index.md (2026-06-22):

# Hsiwu — Technical Documentation (English)

## Contents

- [Theory of Operation](theory_of_operation.md) — Detailed electronics design:
  power supply, NE555 astable timing, 74HC04 phase inversion, L293D motor
  drive, system-level timing, and design rationale.
- [Mechanical Design](mechanical_design.md) — Kinematic foundations:
  crank-rocker four-bar linkage, flapping angle analysis, lead screw &
  scissor mechanism, structural frame, motor & coupling, manufacturing notes.
- [Assembly Guide](assembly_guide.md) — Step-by-step assembly: PCB soldering,
  power-up testing, mechanical assembly sequence, final integration test,
  tuning, and maintenance.

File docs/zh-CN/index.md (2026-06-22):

# Hsiwu — 技术文档（中文）

## 目录

- [工作原理](theory_of_operation.md) — 电子系统详细设计：电源供应、NE555多谐振荡器时序、74HC04相位反相、L293D电机驱动、系统级时序及设计理由。
- [机械设计](mechanical_design.md) — 运动学基础：曲柄摇杆四连杆机构、扑动角度分析、丝杠与剪式机构、结构框架、电机与联轴器、制造注意事项。
- [组装指南](assembly_guide.md) — 逐步组装说明：PCB焊接、上电测试、机械装配顺序、最终集成测试、调校与维护。

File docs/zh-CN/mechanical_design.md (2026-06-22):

# 机械设计 — Hsiwu

## 设计理念

Hsiwu 机械结构围绕三个原则设计：

1. **仿生保真度** — 分段翅膀运动学必须忠实地再现真实蝙蝠（以中华鼠耳蝠 *Rhinolophus luctus* 为形态学参考）翼膜的耦合扑动-伸展运动。
2. **可制造性** — 所有结构部件均可在标准消费级 FDM 3D 打印机上无需支撑打印。
3. **模块化** — 子装配体各自独立；损坏的翅膀段落或连杆可单独更换，无需重印整个机器人。

## 运动学基础

### 曲柄摇杆四连杆机构

将电机连续旋转转化为翅膀往复扑动的核心机构是**曲柄摇杆四连杆机构**（格拉霍夫类型：曲柄摇杆）。

```
                         连杆（rod_bc）
                    ┌─────────────────────────────┐
                    │                             │
    曲柄（rod_a）──┤                             ├── 摇杆（rod_d）
    （固定在电机     │                             │   （输出至翅膀段落）
     轴上，360° CW  │                             │
     连续旋转）      │                             │
                    │      机架（固定连杆）          │
                    └─────────────────────────────┘
```

**格拉霍夫条件：** 曲柄摇杆存在的条件是，最短杆与最长杆长度之和小于其余两杆长度之和：
```
s + l < p + q
```
其中 s = 最短杆，l = 最长杆，p、q 为其余两杆。

在 Hsiwu 连杆机构中：
- **曲柄**（rod_a）= 最短杆 — 由电机驱动，连续旋转
- **连杆**（rod_bc）= 中间件 — 将运动传递给摇杆
- **摇杆**（rod_d）= 输出件 — 以约 70° 幅度摆动
- **机架** = 机械框架（电机轴与摇杆枢轴之间的距离）

### 扑动角度

摇杆角行程（扑动角度）由连杆几何决定：
```
θ_max = arcsin((r_曲柄 + r_连杆) / r_摇杆)  [近似上界]
θ_min = arcsin((r_曲柄 - r_连杆) / r_摇杆)  [近似下界]
扑动幅度 = θ_max − θ_min ≈ 70°
```

### 六种连杆类型

每个翅膀段落（每侧3段）使用各自的连杆组。三组共享相同的运动学拓扑结构，但尺寸可能略有差异，以适应翅膀渐缩的平面形状。

| 连杆 | 角色 | 备注 |
|-----|---|---|
| `rod_a` | 曲柄 | 连接电机输出轴；最短杆 |
| `rod_bc` | 连杆 | 连接曲柄与摇杆；BC 表示共享通用几何的两种变体 |
| `rod_d` | 摇杆 | 输出连杆；驱动翅膀段落 |
| `rod_h` | 辅助连杆 | 连接丝杠驱动螺母 |
| `rod_ij` | 剪式连杆 | 剪式伸缩机构的一部分 |
| `rod_kf` | 连接杆 | 翅膀段落之间的结构连接件 |

## 丝杠与剪式机构

### 设计目的

真实蝙蝠的翼膜不仅扑动，还会**伸展**——翼面弯度在扑翼周期中动态变化。Hsiwu 通过**丝杠驱动剪式连杆机构**复现此特性，在扑动过程中协调地扩展和收缩有效翼面积。

### 机构

```
   电机 → 2转3联轴器 → 丝杠（旋转）
                          │
                 移动螺母（直线平移）
                          │
                 剪式连杆（伸缩）
                          │
                 翼膜面积变化
```

### 丝杠规格

| 参数 | 数值 |
|---|---|
| 螺距（P） | 0.4 mm |
| 有效直径（d₂） | 1.74 mm |
| 驱动力矩（M） | 0.0064 N·mm（计算值） |
| 减速比（电机:丝杠） | 1:4 |

### 力矩计算

参考文献（齐津浩、张卫平，2020）给出丝杠驱动力矩计算式：
```
M = F × d₂/2 × tan(α + ρ)
```
其中：
- F = 螺母轴向载荷
- d₂ = 有效直径
- α = 导程角 = arctan(P / (π·d₂))
- ρ = 摩擦角 = arctan(μ)

取 P = 0.4 mm，d₂ = 1.74 mm，μ ≈ 0.1（钢对塑料）：
```
α = arctan(0.4 / (π × 1.74)) ≈ 4.2°
ρ = arctan(0.1) ≈ 5.7°
M = 0.0064 N·mm
```

### 力学分析

剪式机构以位移换取力。螺母前进 Δx 时，剪式尖端横向位移为 Δy。机械优势为：
```
MA = F_y / F_x ≈ cot(β) / 2
```
其中 β 为剪式半角。剪刀接近闭合时（β → 小），MA 高；接近完全伸展时（β → 大），MA 降低。

## 结构框架

### 中央支撑（`central_support`）

主机身底盘。特征：
- 电机安装座（每侧三个）
- 丝杠轴承座
- PCB 安装柱（轮廓匹配）
- 框架装配用 M2/M3 通孔
- 减重镂空

### 头部支撑与尾部支架

- **头部支撑** — 固定前缘翅膀枢轴和丝杠前端轴承
- **尾部支架** — 固定后缘枢轴点

### 轴承与销钉

- **轴承** — 微型滚珠轴承在两端支撑丝杠，安装在 `center_bearing_cap` 和 `head_bearing_cover` 中
- **头销 / 尾销** — 翅膀段落铰接的精密铰链销

## 电机与联轴器

### 空心杯直流电机

参考电机型号为 ZWPD006006-26，空心杯（无铁芯）直流电机，配四级行星齿轮箱。

**空心杯电机优点：**
- 转子惯量更低 → 方向反转响应更快
- 无齿槽转矩 → 低速运行平稳
- 效率更高 → 电池续航更长

**四级行星齿轮箱：**
- 紧凑形体下实现高减速比
- 输入输出同轴 → 简化机械布局
- 扭矩均匀分配至各行星轮 → 耐久性好

### 2转3轴联轴器

将电机输出轴（直径 2 mm）连接到丝杠输入端（直径 3 mm）。联轴器容纳微量不对中，并通过紧定螺钉传递扭矩。

## 装配体结构

```
final_assembly.SLDASM
├── central_support.SLDPRT                 # 主机身底盘
├── head_support.SLDPRT                    # 前框架件
├── tail_bracket.SLDPRT                    # 后框架件
├── [左翼]
│   ├── rod_a.SLDPRT × 3                   # 曲柄（每段一个）
│   ├── rod_bc.SLDPRT × 3                  # 连杆
│   ├── rod_d.SLDPRT × 3                   # 摇杆
│   ├── rod_h.SLDPRT × 3                   # 辅助连杆
│   ├── rod_ij.SLDPRT × 3                  # 剪式连杆
│   ├── rod_kf.SLDPRT × 3                  # 连接杆
│   └── motor.SLDASM × 3                   # 电机装配体
├── [右翼 — 左翼镜像]
├── lead_screw.SLDPRT                      # 丝杠轴
├── head_drive_shaft.SLDPRT                # 驱动轴
├── bearing.SLDPRT × 2                     # 轴承
├── center_bearing_cap.SLDPRT              # 轴承固定盖
├── head_bearing_cover.SLDPRT              # 轴承端盖
├── head_pin.SLDPRT                        # 前缘枢轴销
├── tail_pin.SLDPRT                        # 后缘枢轴销
└── [紧固件]
    ├── SCA_M2_L10.SLDPRT                  # M2 × 10mm 沉头螺丝
    ├── SCA_M2_L12.SLDPRT                  # M2 × 12mm
    ├── SCA_M2_L14.SLDPRT                  # M2 × 14mm
    ├── SCA_M2_L18.SLDPRT                  # M2 × 18mm
    ├── SLMNA-M2.SLDPRT                    # M2 防松螺母
    └── SLMNA-M3.SLDPRT                    # M3 防松螺母
```

## 制造注意事项

### FDM 3D 打印

| 设置 | 数值 |
|---|---|
| 层高 | 0.2 mm |
| 喷嘴直径 | 0.4 mm |
| 填充 | 20–30%（螺旋或网格） |
| 外壳圈数 | 3 |
| 支撑 | 无需 |
| 材料 | ABS（耐用）或 PLA+（易打印） |

### 激光切割（连杆）

连杆可采用激光切割亚克力或胶合板，替代 3D 打印方案，提供更好的尺寸精度：
- 2–3 mm 厚亚克力板
- STL 文件位于 `mechanical/output/laser/`
- 切割后：去毛刺，试配轴承

### 装配提示

1. **先装轴承** — 在组装框架前将微型轴承压入其安装座
2. **预装配** — 不装螺丝先试装，验证所有间隙
3. **螺纹锁固** — 电机安装螺丝使用微量螺纹锁固剂（低强度，如 Loctite 222）
4. **连杆对齐** — 在连接电机之前验证所有四连杆机构在全行程范围内自由运动
5. **布线** — 电机导线沿框架内部通道走线至 PCB XH-2A 连接器

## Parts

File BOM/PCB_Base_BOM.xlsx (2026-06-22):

No. | Quantity | Comment | Designator | Footprint | Value | Manufacturer Part | Manufacturer | Supplier Part | Supplier
1 | 2 | 22uF | C1,C2 | C0805 | 22uF | CGA0805X5R226M350MT | HRE(芯声) | C6119901 | LCSC
2 | 3 | 10uF | C3,C5,C7 | CAP-SMD_BD4.0-L4.3-W4.3-LS5.1-FD | 10uF | JVJ25V10M4x6 | JIERR(捷而瑞) | C46550403 | LCSC
3 | 3 | 100nF | C4,C6,C8 | C0805 | 100nF | CL21B104KBCNNNC | SAMSUNG(三星) | C1711 | LCSC
4 | 1 | SS34 | D1 | SMC_L6.9-W5.9-LS7.9-RD |  | SS34 | onsemi(安森美) | C154551 | LCSC
5 | 1 | 10uH | L1 | IND-SMD_L7.3-W6.8 | 10uH | FXL0630-100-M | cjiang(长江微电) | C167223 | LCSC
6 | 1 | GL0805UG01 | LED1 | LED0805-FD |  | GL0805UG01 | Guiguang light(桂光光电) | C51933308 | LCSC
7 | 1 | 16kΩ | R1 | R0805 | 16kΩ | 0805W8F1602T5E | UNI-ROYAL(厚声) | C17490 | LCSC
8 | 1 | 2.2kΩ | R2 | R0805 | 2.2kΩ | 0805W8F2201T5E | UNI-ROYAL(厚声) | C17520 | LCSC
9 | 3 | 10kΩ | R3,R5,R7 | R0805 | 10kΩ | 0805W8F1002T5E | UNI-ROYAL(厚声) | C17414 | LCSC
10 | 3 | 100kΩ | R4,R10,R11 | RES-ADJ-SMD_JER33X-1-14 | 100kΩ | JER33X-1-15 | JIERR(捷而瑞) | C48997895 | LCSC
11 | 1 | 1kΩ | R6 | R0805 | 1kΩ | 0805W8F1001T5E | UNI-ROYAL(厚声) | C17513 | LCSC
12 | 1 | SS12D07VG4 087 | SW2 | SW-TH_SS12D07VG4 |  | SS12D07VG4 087 | SHOU HAN(首韩) | C2939726 | LCSC
13 | 3 | L293DD013TR | U1,U2,U3 | SOP-20_L13.2-W7.8-P1.27-LS10.4-BL |  | L293DD013TR | ST(意法半导体) | C21610 | LCSC
14 | 1 | MT3608 | U4 | SOT-23-6_L2.9-W1.6-P0.95-LS2.8-BL |  | MT3608 | 西安航天民芯 | C84817 | LCSC
15 | 1 | 74HC04D,653 | U5 | SOIC-14_L8.7-W3.9-P1.27-LS6.0-BL |  | 74HC04D,653 | Nexperia(安世) | C5590 | LCSC
16 | 3 | NE555DR | U6,U7,U8 | SOIC-8_L4.9-W3.9-P1.27-LS6.0-BL |  | NE555DR | TI(德州仪器) | C7593 | LCSC
17 | 1 | WAFER-XH254Z-2AM | U9 | CONN-TH_2P-P2.50_XH-2A_3045048 |  | WAFER-XH254Z-2AM | HANBO(汉博) | C22751822 | LCSC

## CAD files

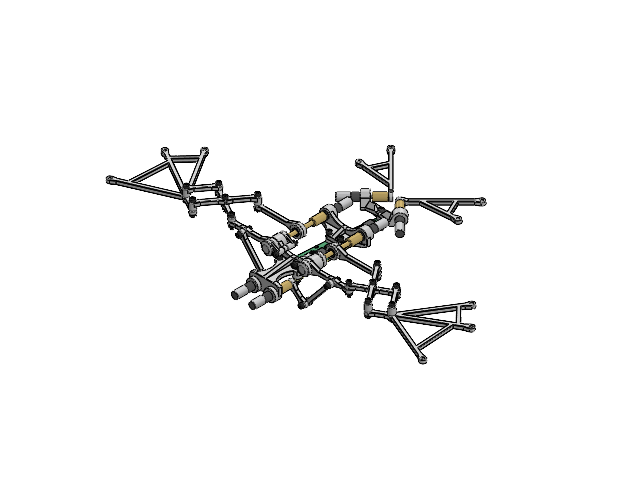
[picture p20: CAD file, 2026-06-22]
mechanical/source/assembly/final_assembly.SLDASM
Board~AfwL
SOP-20_L13.2-W7.8-P1.27-LS10.4-BL~SOP-20_L12.8-W7.5-H2.5-LS10.3-P1.27~AfwL x 3
SOT-23-6_L2.9-W1.6-P0.95-LS2.8-BL~SOT-23-6_L2.9-W1.6-H1.5-LS2.8-P0.95~AfwL
SOIC-14_L8.7-W3.9-P1.27-LS6.0-BL~SOIC-14_L8.6-W3.9-H1.8-LS6.0-P1.27~AfwL
SOIC-8_L4.9-W3.9-P1.27-LS6.0-BL~SOIC-8_L4.9-W3.9-H1.7-LS6.0-P1.27~AfwL x 3
CAP-SMD_BD4.0-L4.3-W4.3-LS5.1-FD~CAP-SMD_BD4.0-L4.3-W4.3-LS5.1-FD~AfwL x 3
SMC_L6.9-W5.9-LS7.9-RD~SMC_L6.9-W5.9-LS7.9-RD~AfwL
IND-SMD_L7.3-W6.8~IND-SMD_L7.3-W6.8-H3.0~AfwL
CONN-TH_2P-P2.50_XH-2A_3045048~CONN-TH_2P-P2.50_XH-2A_3045048~AfwL
RES-ADJ-SMD_JER33X-1-14~RES-ADJ-SMD_JER33X-1-14~AfwL x 3
SW-TH_SS12D07VG4~SW-TH_SS12D07VG4~AfwL
C0805~C0805_L2.0-W1.3-H1.3~AfwL x 5
LED0805-FD~LED0805_Inf~AfwL
R0805~R0805_L2.0-W1.3-H0.6~AfwL x 6
tail_bracket
central_support
head_support
2-to-3_coupling x 6
four-stage_geared_hollow_cup_motor x 6
tail_pin x 2
bearing x 4
center_bearing_cap x 2
lead_screw x 2
head_bearing_cover x 2
rod_a x 2
head_pin x 2
head_drive_shaft x 2
rod_h x 2
SLMNA-M3 x 2
rod_ij x 2
rod_bc x 2
rod_d x 2
rod_kf x 2
SCA_M2_L14
SCA_M2_L12 x 10
SCA_M2_L18 x 2
SCA_M2_L10 x 10
SLMNA-M2 x 21

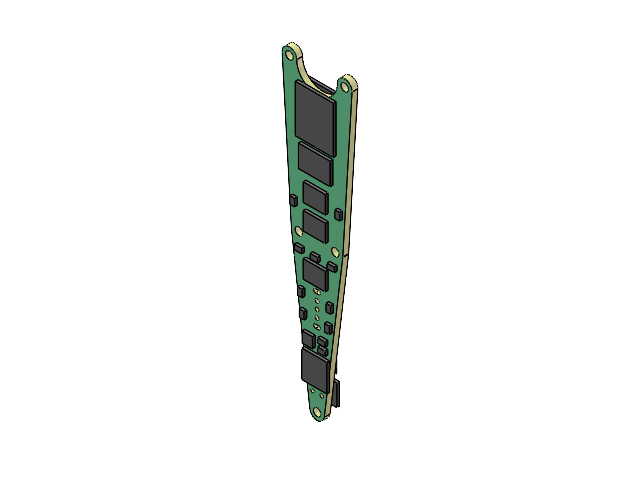
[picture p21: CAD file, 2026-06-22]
mechanical/source/pcb_3d_models/PCB.SLDASM
Board~AfwL
SOP-20_L13.2-W7.8-P1.27-LS10.4-BL~SOP-20_L12.8-W7.5-H2.5-LS10.3-P1.27~AfwL x 3
SOT-23-6_L2.9-W1.6-P0.95-LS2.8-BL~SOT-23-6_L2.9-W1.6-H1.5-LS2.8-P0.95~AfwL
SOIC-14_L8.7-W3.9-P1.27-LS6.0-BL~SOIC-14_L8.6-W3.9-H1.8-LS6.0-P1.27~AfwL
SOIC-8_L4.9-W3.9-P1.27-LS6.0-BL~SOIC-8_L4.9-W3.9-H1.7-LS6.0-P1.27~AfwL x 3
CAP-SMD_BD4.0-L4.3-W4.3-LS5.1-FD~CAP-SMD_BD4.0-L4.3-W4.3-LS5.1-FD~AfwL x 3
SMC_L6.9-W5.9-LS7.9-RD~SMC_L6.9-W5.9-LS7.9-RD~AfwL
IND-SMD_L7.3-W6.8~IND-SMD_L7.3-W6.8-H3.0~AfwL
CONN-TH_2P-P2.50_XH-2A_3045048~CONN-TH_2P-P2.50_XH-2A_3045048~AfwL
RES-ADJ-SMD_JER33X-1-14~RES-ADJ-SMD_JER33X-1-14~AfwL x 3
SW-TH_SS12D07VG4~SW-TH_SS12D07VG4~AfwL
C0805~C0805_L2.0-W1.3-H1.3~AfwL x 5
LED0805-FD~LED0805_Inf~AfwL
R0805~R0805_L2.0-W1.3-H0.6~AfwL x 6

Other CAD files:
mechanical/source/pcb_3d_models/L1~IND-SMD_L7.3-W6.8~IND-SMD_L7.3-W6.8-H3.0~AfwL.SLDASM
mechanical/source/pcb_3d_models/R3~R0805~R0805_L2.0-W1.3-H0.6~AfwL.SLDASM
mechanical/source/pcb_3d_models/LED1~LED0805-FD~LED0805_Inf~AfwL.SLDASM
mechanical/source/pcb_3d_models/R1~R0805~R0805_L2.0-W1.3-H0.6~AfwL.SLDASM
mechanical/source/pcb_3d_models/C2~C0805~C0805_L2.0-W1.3-H1.3~AfwL.SLDASM
mechanical/source/pcb_3d_models/U3~SOP-20_L13.2-W7.8-P1.27-LS10.4-BL~SOP-20_L12.8-W7.5-H2.5-LS10.3-P1.27~AfwL.SLDASM
mechanical/source/pcb_3d_models/U9~CONN-TH_2P-P2.50_XH-2A_3045048~CONN-TH_2P-P2.50_XH-2A_3045048~AfwL.SLDASM
mechanical/source/pcb_3d_models/R4~RES-ADJ-SMD_JER33X-1-14~RES-ADJ-SMD_JER33X-1-14~AfwL.SLDASM
mechanical/source/pcb_3d_models/C6~C0805~C0805_L2.0-W1.3-H1.3~AfwL.SLDASM
mechanical/source/pcb_3d_models/R11~RES-ADJ-SMD_JER33X-1-14~RES-ADJ-SMD_JER33X-1-14~AfwL.SLDASM
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

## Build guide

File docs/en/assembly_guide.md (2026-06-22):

# Assembly Guide — Hsiwu

This guide covers the complete assembly of the Hsiwu biomimetic bat robot
from manufactured parts to a fully functional flapping-wing system.

---

## Prerequisites

### Tools Required
- Soldering iron (temperature-controlled, fine tip)
- Solder (lead-free or 63/37 SnPb, 0.5–0.8 mm diameter)
- Solder wick / desoldering pump
- Tweezers (fine-point, anti-magnetic)
- Flux pen (no-clean)
- Digital multimeter (DMM)
- Oscilloscope (optional but recommended — Tektronix TDS1001B-SC or equivalent)
- Hex drivers: 1.5 mm, 2.0 mm
- Small Phillips screwdriver (#00, #0)
- Needle-nose pliers
- Flush cutters
- Third-hand tool / PCB vise
- Isopropyl alcohol (99%) + brush for PCB cleaning
- FDM 3D printer (if printing parts yourself)
- Digital calipers

### Materials
- Fabricated PCB (from Gerber files in `electronics/output/gerber/`)
- All components from the BOM (`BOM/PCB_Base_BOM.xlsx`)
- 3D-printed structural parts (STEP files in `mechanical/output/3dp/`)
- Laser-cut or 3D-printed rods
- M2/M3 screws and lock nuts
- 3.7V LiPo battery (single-cell)
- Motor wires (26–28 AWG stranded)
- Double-sided foam tape (for battery mounting)

---

## Step 1: PCB Assembly

### 1.1 Inspection
Before soldering, inspect the bare PCB:
- [ ] No visible shorts between adjacent traces (use magnifying glass)
- [ ] All pads are intact, no lifted pads
- [ ] Silkscreen is legible (component designators match BOM)
- [ ] Board outline matches mechanical frame contour

### 1.2 Soldering Order
Solder components from **smallest to tallest** and **lowest thermal mass first**:

1. **0805 Resistors** (R1–R11) — ceramic, robust to heat
2. **0805 Capacitors** (C1–C2, C4, C6, C8) — small MLCCs
3. **0805 LED** (LED1) — observe polarity (cathode mark)
4. **SOT-23-6** (U4, MT3608) — fine pitch, use flux
5. **SOIC-8** (U6, U7, U8 — L293D) — align pin 1 marker
6. **SOIC-14** (U5 — 74HC04) — align pin 1 marker
7. **SOP-20** (U1, U2, U3 — NE555 carriers) — use drag soldering
8. **SMC Diode** (D1) — observe polarity (cathode band)
9. **SMD Inductor** (L1) — large thermal mass, pre-heat pad
10. **SMD Electrolytics** (C3, C5, C7) — observe polarity
11. **Thru-hole Switch** (SW2) — solder from bottom side
12. **XH-2A Connectors** (U9 × 3) — ensure they sit flat
13. **Battery connector** — wire leads, strain relief

### 1.3 Soldering Tips

**For 0805 passives:**
1. Tin one pad
2. Hold component with tweezers, reflow tinned pad
3. Solder the other pad
4. Reflow the first pad for a clean joint

**For SOIC/SOP ICs:**
1. Align pin 1 (dot/notch) with silkscreen marker
2. Tack two opposite corner pins
3. Apply flux to all pins
4. Drag solder along each row
5. Remove bridges with solder wick

### 1.4 Post-Solder Inspection
- [ ] Visual inspection of all joints (shiny, concave fillet, no bridges)
- [ ] Continuity test: power rails not shorted to ground
  - DMM in continuity mode: probe between VCC and GND — should be open
- [ ] Diode test: D1 cathode → anode should be open (DMM diode mode)

---

## Step 2: PCB Power-Up Test

**Before connecting motors**, verify the power supply:

1. **Set up** — PCB on insulated surface, oscilloscope probes ready
2. **Check input** — DMM on battery terminals: 3.7–4.2 V
3. **Power on** — slide SW2 to ON
4. **Verify LED** — LED1 should illuminate green
5. **Measure rails**:
   - 5 V rail: DMM between any IC's VCC and GND → 5.0 V ± 0.25 V
   - 7.35 V rail: DMM between L293D pin 8 (VCC2) and GND → 7.35 V ± 0.5 V
6. **Check oscillation** (oscilloscope):
   - Probe NE555 output pins (U1/U2/U3 pin 3)
   - Should see ~4.8 Hz square wave, 0 V to ~5 V
   - Check all three channels
7. **Verify phase inversion** (2-channel scope):
   - Ch1: NE555 OUT
   - Ch2: 74HC04 corresponding /OUT
   - Should be complementary (one HIGH when the other is LOW)

> **If any check fails:** power off immediately and debug. Common issues:
> - No 5 V: check LDO, C2, C4
> - No 7.35 V: check MT3608 feedback resistors, L1, D1
> - No oscillation: check RC network, trimmer position
> - Wrong phase: check 74HC04 pin connections

---

## Step 3: Mechanical Assembly

### 3.1 3D-Printed Parts Checklist

| Part | Qty | Print File |
|---|-----|---|
| `central_support` | 1 | `mechanical/output/3dp/central_support.STEP` |
| `head_support` | 1 | `mechanical/output/3dp/head_support.STEP` |
| `tail_bracket` | 1 | `mechanical/output/3dp/tail_bracket.STEP` |
| `head_bearing_cover` | 1 | `mechanical/output/3dp/head_bearing_cover.STEP` |
| `center_bearing_cap` | 1 | `mechanical/output/3dp/center_bearing_cap.STEP` |
| `head_drive_shaft` | 1 | `mechanical/output/3dp/head_drive_shaft.STEP` |
| `head_pin` | 2 | `mechanical/output/3dp/head_pin.STEP` |
| `tail_pin` | 2 | `mechanical/output/3dp/tail_pin.STEP` |

### 3.2 Rods Checklist

| Rod | Qty (total) | Notes |
|-----|---|---|
| `rod_a` | 6 | 3 per side — crank |
| `rod_bc` | 6 | 3 per side — coupler |
| `rod_d` | 6 | 3 per side — rocker |
| `rod_h` | 6 | 3 per side — auxiliary |
| `rod_ij` | 6 | 3 per side — scissor |
| `rod_kf` | 6 | 3 per side — tie |

### 3.3 Fasteners Checklist

| Fastener | Approx. Qty | Where Used |
|---|---|---|
| M2 × 10 mm CSK | ~8 | Frame to central support |
| M2 × 12 mm CSK | ~6 | Motor mounts |
| M2 × 14 mm CSK | ~4 | Bearing caps |
| M2 × 18 mm CSK | ~4 | Head/tail support through-bolts |
| M2 lock nut | ~22 | All M2 screws |
| M3 lock nut | ~4 | Frame major joints |

### 3.4 Assembly Sequence

#### 3.4.1 Frame Sub-Assembly
1. Insert bearings into `center_bearing_cap` and `head_bearing_cover`
2. Mount `head_support` to `central_support` with M2 × 10 mm screws
3. Mount `tail_bracket` to `central_support` with M2 × 10 mm screws
4. Install `lead_screw` with bearings and caps
5. Install `head_drive_shaft`
6. Insert `head_pin` and `tail_pin` into their pivot seats

#### 3.4.2 Motor Installation
1. Mount three hollow-cup motors to the motor bosses on `central_support`
   (M2 × 12 mm)
2. Attach `2-to-3_coupling` to each motor shaft
3. Verify motor shafts rotate freely by hand

#### 3.4.3 Linkage Assembly (per wing segment)
1. Attach `rod_a` (crank) to motor output → secure with set screw
2. Connect `rod_bc` (coupler) to `rod_a` with hinge pin
3. Connect `rod_d` (rocker) to `rod_bc` and to wing pivot pin
4. Attach `rod_h`, `rod_ij`, `rod_kf` for scissor linkage
5. **Repeat for all three segments per side**
6. **Mirror for the opposite wing**

#### 3.4.4 PCB Mounting
1. Place PCB onto the standoffs on `central_support`
2. Secure with M2 screws (do not overtighten — FR-4 can crack)
3. Route motor wires to the XH-2A connectors
4. Use zip ties or small adhesive clips for wire management

#### 3.4.5 Battery Installation
1. Mount the LiPo battery on the underside of `central_support`
2. Use double-sided foam tape + a velcro strap
3. Connect battery to PCB input

---

## Step 4: Final Integration Test

### 4.1 Pre-Flight Checklist
- [ ] All screws tightened (but not stripped)
- [ ] All linkages move freely through full range of motion
- [ ] No wires rubbing against moving parts
- [ ] Battery secured and connected
- [ ] PCB mounted firmly
- [ ] All XH-2A connectors fully seated

### 4.2 Power-On Sequence
1. Place robot on a soft surface (foam pad or towel)
2. Slide SW2 to ON
3. LED1 should illuminate
4. Wings should begin flapping within ~1 second
5. All three segments per wing should move in a coordinated wave

### 4.3 Tuning
- **Wing 1 (leading edge) speed** — adjust R4 trimmer
- **Wing 2 (middle) speed** — adjust R10 trimmer
- **Wing 3 (trailing edge) speed** — adjust R11 trimmer
- **Ideal pattern**: leading edge leads slightly, trailing edge follows —
  creates the bat's characteristic "wave" motion

### 4.4 Common Issues

| Symptom | Likely Cause | Fix |
|---|---|-----|
| One motor doesn't run | Bad solder joint on L293D or XH-2A | Reflow joints |
| Motor runs only one direction | 74HC04 channel not inverting | Check 74HC04 input connection |
| Wing binds mid-stroke | Linkage interference | Adjust rod lengths or clearances |
| Flapping too fast/slow | RC timing off | Adjust trimmer |
| No power LED | Dead battery or reversed polarity | Check battery, check D1 |
| Excessive noise | Loose screw or dry bearing | Tighten, lubricate bearing |

---

## Step 5: Maintenance

- **Bearings**: Apply a tiny drop of light machine oil every ~10 hours of
  operation
- **Linkage joints**: Inspect for wear every ~5 hours; replace rods if
  slop develops
- **PCB**: Clean with isopropyl alcohol if flux residue attracts dust
- **Battery**: Store at 3.7–3.8 V (storage charge) when not in use
- **Motors**: Brushes have finite life; expect ~50–100 hours of continuous
  operation before replacement

---

**Happy flying!** 🦇

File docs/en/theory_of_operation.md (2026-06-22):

# Theory of Operation — Hsiwu Electronics

## Overview

The Hsiwu control system generates three synchronized, independent
reciprocating motor drive signals using purely analog and digital logic
components — no microcontroller, no firmware, no programmable logic.

## Block Diagram

```
                   +-----------+
  3.7V LiPo ──────│ POWER     │──── 7.35V ────────────── Motor Rail (L293D VCC2)
                   │ SUPPLY    │
                   │           │──── 5.0V ───┬────────── Logic Rail (NE555, 74HC04, L293D VCC1)
                   +-----------+             │
                                             │
              ┌──────────────────────────────┤
              │                              │
       ┌──────┴──────┐               ┌──────┴──────┐
       │ NE555 (U1)  │               │ NE555 (U2)  │  ...
       │ Astable     │               │ Astable     │
       │ ~4.8 Hz     │               │ ~4.8 Hz     │
       └──────┬──────┘               └──────┬──────┘
              │ OUT1                        │ OUT2
       ┌──────┴──────────────────────┐     │
       │       74HC04 (U5)           │     │
       │  ┌─ NOT ─ /OUT1             │     │
       │  ├─ NOT ─ /OUT2             │◄────┘
       │  └─ NOT ─ /OUT3             │
       └──────┬──────────────────────┘
              │
    ┌─────────┼─────────┐
    │   OUT1  │  /OUT1  │
    ▼         ▼         ▼
  ┌──────────────┐
  │ L293D (U6)   │──── Motor 1 (Leading Edge)
  │ Half-Bridge  │
  └──────────────┘
  (same for U7/Motor 2/Middle, U8/Motor 3/Trailing)
```

## Stage 1: Power Supply

### Input Protection
- **D1** (Schottky diode, SMC package) — reverse-polarity protection. If the
  battery is connected backwards, D1 blocks current flow.
- **SW2** (SS12D07VG4 slide switch) — master power on/off.
- **LED1** (green 0805) — power-on indicator with current-limiting resistor.

### Boost Converter (MT3608, U4)
The MT3608 is a fixed-frequency (1.2 MHz) current-mode boost converter.

- **Input**: 3.7 V (single-cell LiPo, nominal)
- **Output**: 7.35 V (set by feedback resistor divider)
- **Inductor** (L1): SMD shielded power inductor, 7.3×6.8 mm
- **Input capacitor**: 10 µF (C1, 0805 X7R or X5R)
- **Output capacitor**: 22 µF (C3, SMD aluminum electrolytic equivalent)

The output voltage is given by:
```
V_OUT = V_REF × (1 + R1/R2)
```
where V_REF ≈ 0.6 V (MT3608 internal reference), and R1, R2 form the feedback
divider.

### LDO Regulator
- A linear regulator drops the 7.35 V boost output to a clean 5.0 V rail for
  the logic ICs (NE555, 74HC04) and L293D logic supply (VCC1).
- Decoupling capacitors (C2, C4) are placed close to the IC power pins.

## Stage 2: Timing Generation (NE555 Astable)

Each NE555 (U1, U2, U3) is configured in **astable multivibrator** mode.
In this mode, the output oscillates continuously between HIGH (≈ VCC) and
LOW (≈ 0 V) with no external trigger.

### Circuit Configuration

```
           VCC
            │
           ─┼─ R_A ──┬── R_B ──┬── VCC
            │        │         │
            │        ├── Pin 7 (DISCH)
            │        │
            ├────────┼── Pin 6,2 (THRES, TRIG)
            │        │
            │       ─┼─ C
            │        │
           ─┴────────┴── GND
```

### Timing Equations

**Output HIGH time (t_H):**
```
t_H = 0.693 × (R_A + R_B) × C
```

**Output LOW time (t_L):**
```
t_L = 0.693 × R_B × C
```

**Period:**
```
T = t_H + t_L = 0.693 × (R_A + 2·R_B) × C
```

**Frequency:**
```
f = 1/T = 1.44 / ((R_A + 2·R_B) × C)
```

### Design Values (for ~4.8 Hz)

| Parameter | Value | Notes |
|---|---|---|
| R_A | ~10 kΩ (fixed + trimmer) | R + R4 (trimmer) for U1 |
| R_B | ~100 kΩ | Fixed 0805 resistor |
| C | ~1 µF | Ceramic or tantalum |
| **Target f** | ~4.8 Hz | ≈ 10 Hz reference scaled down |
| **Target T** | ~208 ms | |
| **Duty cycle** | ~52% | Slightly asymmetric by design |

**Frequency fine-tuning:** Each NE555 stage has an adjustable resistor (R4 for
U1, R10 for U2, R11 for U3) — 3-terminal SMD trimmer potentiometers. Adjusting
these changes R_A and therefore the oscillation frequency, allowing per-segment
timing calibration.

### Start-Up Synchronization

All three NE555s share the same VCC rail and have similar RC networks. They
tend to power up nearly synchronized, but small component tolerances cause
them to drift. The 74HC04 stage ensures that regardless of relative phase,
each motor always has complementary drive signals.

## Stage 3: Phase Inversion (74HC04)

The 74HC04 is a hex inverter (six independent NOT gates). Only three gates
are used:

| Gate | Input | Output | Purpose |
|---|---|---|---|
| 1A → 1Y | NE555 U1 OUT | /OUT1 | Inverted drive for L293D U6 |
| 2A → 2Y | NE555 U2 OUT | /OUT2 | Inverted drive for L293D U7 |
| 3A → 3Y | NE555 U3 OUT | /OUT3 | Inverted drive for L293D U8 |

Each NE555 output is connected to its corresponding L293D input pin **and** to
a 74HC04 input. The inverted output goes to the complementary L293D input pin.

### Signal Relationships

```
NE555 OUT = HIGH → L293D IN1 = HIGH, IN2 = LOW  → Motor FORWARD
NE555 OUT = LOW  → L293D IN1 = LOW,  IN2 = HIGH → Motor REVERSE
```

This creates the continuous forward/reverse reciprocation.

### Unused Gates

The three unused inverter gates (4A/4Y, 5A/5Y, 6A/6Y) should have their inputs
tied to GND to prevent floating-input oscillation and excess current draw.

## Stage 4: Motor Drive (L293D)

The L293D is a dual H-bridge driver capable of 600 mA per channel (1.2 A peak).

### Pin Configuration (per motor, using one half-bridge)

| L293D Pin | Connection | Purpose |
|---|---|---|
| VCC1 (pin 16) | 5 V rail | Logic supply |
| VCC2 (pin 8) | 7.35 V rail | Motor power supply |
| 1,2EN (pin 1) | 5 V (always enabled) | Half-bridge 1-2 enable |
| 1A (pin 2) | NE555 OUT | Input A — direction control |
| 2A (pin 7) | 74HC04 /OUT | Input B — complementary direction |
| 1Y (pin 3) | Motor terminal + | Output to motor |
| 2Y (pin 6) | Motor terminal − | Output to motor |
| GND (pins 4,5,12,13) | Common ground | Power + logic return |

### Truth Table

| 1A (IN1) | 2A (IN2) | Motor |
|---|---|---|
| H | L | Forward (7.35 V across motor) |
| L | H | Reverse (−7.35 V across motor) |
| L | L | Brake (motor terminals shorted to GND) |
| H | H | Brake (motor terminals shorted to VCC2) |

In normal operation, 1A and 2A are always complementary, so the motor is
always driving forward or reverse — never braking. Brake states only occur
for a few nanoseconds during logic transitions.

### Built-in Protection

The L293D includes:
- **Flyback diodes** on all outputs — no external diodes needed
- **Thermal shutdown** — protects against over-temperature
- **Over-current limiting** — internal current limiting

## System-Level Timing

The complete signal chain for one wing segment:

```
t = 0:    NE555 OUT goes HIGH
          → L293D IN1 = HIGH, IN2 = LOW
          → Motor drives FORWARD
          → Wing segment moves UP (flapping)

t = t_H:  NE555 OUT goes LOW (~108 ms later, at ~52% duty)
          → L293D IN1 = LOW, IN2 = HIGH
          → Motor drives REVERSE
          → Wing segment moves DOWN (return stroke)

t = T:    NE555 OUT goes HIGH again (~208 ms total)
          → Cycle repeats at ~4.8 Hz
```

## Design Rationale

### Why NE555?

- **Simplicity** — three external components (R_A, R_B, C) set the frequency
- **Wide supply range** — 4.5 V to 16 V, compatible with 5 V logic rail
- **Sufficient drive** — can source/sink 200 mA, more than enough for driving
  74HC04 inputs and L293D logic inputs
- **Well-characterized** — the NE555 is one of the most documented ICs ever made

### Why 74HC04 Instead of Direct Complementary NE555 Outputs?

The NE555 output stage is a totem-pole (push-pull) — it only provides a single
output. A complementary output would require an external transistor inverter
or logic gate. The 74HC04 provides six inverters in one package, using only
three for the three NE555 channels — clean and compact.

### Why ~4.8 Hz (Instead of the Reference Paper's ~10 Hz)?

The reference prototype (Qi & Zhang, 2020) achieves ~10 Hz flapping. The Hsiwu
design targets ~4.8 Hz — about half the frequency — for several reasons:

1. **Larger amplitude per stroke** — slower flapping allows the wing to reach
   its full 70° stroke without aerodynamic damping cutoff
2. **Reduced mechanical stress** — lower cyclic loading on the 3D-printed
   linkages and frame
3. **Observability** — at 4.8 Hz, the segmented membrane deformation is
   visually distinguishable
4. **Motor current headroom** — lower frequency means lower average current
   draw from the single-cell LiPo

The frequency can be increased by adjusting the three trimmer resistors
(R4, R10, R11) to reduce R_A, up to the mechanical limits of the system.

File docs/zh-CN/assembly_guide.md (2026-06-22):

# 组装指南 — Hsiwu

本指南涵盖 Hsiwu 仿生蝙蝠机器人从制造零件到完全运行的扑翼系统的完整组装过程。

---

## 准备工作

### 所需工具
- 电烙铁（温控型，细尖头）
- 焊锡（无铅或 63/37 SnPb，直径 0.5–0.8 mm）
- 吸锡带 / 吸锡器
- 镊子（尖头，防磁）
- 助焊笔（免清洗型）
- 数字万用表（DMM）
- 示波器（可选但推荐 — Tektronix TDS1001B-SC 或同等型号）
- 六角螺丝刀：1.5 mm、2.0 mm
- 小型十字螺丝刀（#00、#0）
- 尖嘴钳
- 斜口钳
- 第三手工具 / PCB 夹具
- 异丙醇（99%）+ 刷子（清洗 PCB）
- FDM 3D 打印机（如自行打印零件）
- 数显游标卡尺

### 所需材料
- 制成品 PCB（来自 `electronics/output/gerber/` 中的 Gerber 文件）
- BOM 清单所列全部元件（`BOM/PCB_Base_BOM.xlsx`）
- 3D 打印结构件（STEP 文件位于 `mechanical/output/3dp/`）
- 激光切割或 3D 打印连杆
- M2/M3 螺丝及防松螺母
- 3.7V 锂电池（单节）
- 电机线（AWG 26–28 绞线）
- 双面泡沫胶（固定电池用）

---

## 步骤1：PCB 组装

### 1.1 检查
焊接前检查裸板：
- [ ] 相邻走线无可见短路（使用放大镜检查）
- [ ] 所有焊盘完整无损
- [ ] 丝印清晰可辨（元件编号与 BOM 一致）
- [ ] 板外形与机械框架轮廓吻合

### 1.2 焊接顺序
按**从小到大**、**从低热质量到高热质量**的顺序焊接：

1. **0805 电阻**（R1–R11） — 陶瓷，耐热
2. **0805 电容**（C1–C2、C4、C6、C8） — MLCC 小电容
3. **0805 LED**（LED1） — 注意极性（阴极标记）
4. **SOT-23-6**（U4，MT3608） — 细间距，使用助焊剂
5. **SOIC-8**（U6、U7、U8 — L293D） — 对齐引脚1标记
6. **SOIC-14**（U5 — 74HC04） — 对齐引脚1标记
7. **SOP-20**（U1、U2、U3 — NE555 载板） — 使用拖焊法
8. **SMC 二极管**（D1） — 注意极性（色带为阴极）
9. **SMD 电感**（L1） — 大热质量，预热焊盘
10. **SMD 电解电容**（C3、C5、C7） — 注意极性
11. **直插开关**（SW2） — 从底面焊接
12. **XH-2A 连接器**（U9 × 3） — 确保平贴板面
13. **电池连接器** — 线头焊接，加应力消除

### 1.3 焊接技巧

**0805 无源元件：**
1. 给一个焊盘上锡
2. 用镊子夹持元件，回流已上锡焊盘
3. 焊接另一焊盘
4. 回流第一个焊盘使其光亮整洁

**SOIC/SOP 芯片：**
1. 将引脚1（圆点/缺口标记）对准丝印标记
2. 点焊固定对角两个引脚
3. 所有引脚涂助焊剂
4. 沿每排引脚拖焊
5. 用吸锡带清除连锡

### 1.4 焊后检查
- [ ] 目视检查所有焊点（光亮、凹形焊脚、无连锡）
- [ ] 通断测试：电源轨对地无短路
  - 万用表通断档：VCC 与 GND 之间探针 — 应为断路
- [ ] 二极管测试：D1 阴→阳应为断路（万用表二极管档）

---

## 步骤2：PCB 上电测试

**连接电机之前**，确认电源正常：

1. **准备工作** — PCB 放在绝缘表面，示波器探头准备就绪
2. **检查输入** — 万用表测量电池端电压：3.7–4.2 V
3. **上电** — 拨动 SW2 至 ON
4. **确认 LED** — LED1 应亮绿色
5. **测量各电压轨**：
   - 5 V 轨：任意 IC 的 VCC 与 GND 之间 → 5.0 V ± 0.25 V
   - 7.35 V 轨：L293D 引脚8（VCC2）与 GND 之间 → 7.35 V ± 0.5 V
6. **检查振荡**（示波器）：
   - 探头接 NE555 输出脚（U1/U2/U3 引脚3）
   - 应看到 ~4.8 Hz 方波，0 V 至 ~5 V
   - 检查全部三路
7. **验证相位反相**（双通道示波器）：
   - 通道1：NE555 OUT
   - 通道2：74HC04 对应 /OUT
   - 应互补（一个 HIGH 时另一个 LOW）

> **如有任何检查未通过：** 立即断电调试。常见问题：
> - 无 5 V：检查 LDO、C2、C4
> - 无 7.35 V：检查 MT3608 反馈电阻、L1、D1
> - 无振荡：检查 RC 网络、微调电位器位置
> - 相位错误：检查 74HC04 引脚连接

---

## 步骤3：机械装配

### 3.1 3D 打印件清单

| 零件 | 数量 | 打印文件 |
|---|-----|---|
| `central_support` | 1 | `mechanical/output/3dp/central_support.STEP` |
| `head_support` | 1 | `mechanical/output/3dp/head_support.STEP` |
| `tail_bracket` | 1 | `mechanical/output/3dp/tail_bracket.STEP` |
| `head_bearing_cover` | 1 | `mechanical/output/3dp/head_bearing_cover.STEP` |
| `center_bearing_cap` | 1 | `mechanical/output/3dp/center_bearing_cap.STEP` |
| `head_drive_shaft` | 1 | `mechanical/output/3dp/head_drive_shaft.STEP` |
| `head_pin` | 2 | `mechanical/output/3dp/head_pin.STEP` |
| `tail_pin` | 2 | `mechanical/output/3dp/tail_pin.STEP` |

### 3.2 连杆清单

| 连杆 | 数量（合计） | 备注 |
|-----|---|---|
| `rod_a` | 6 | 每侧3个 — 曲柄 |
| `rod_bc` | 6 | 每侧3个 — 连杆 |
| `rod_d` | 6 | 每侧3个 — 摇杆 |
| `rod_h` | 6 | 每侧3个 — 辅助 |
| `rod_ij` | 6 | 每侧3个 — 剪式 |
| `rod_kf` | 6 | 每侧3个 — 连接 |

### 3.3 紧固件清单

| 紧固件 | 大约数量 | 使用位置 |
|---|---|---|
| M2 × 10 mm 沉头 | ~8 | 框架至中央支撑 |
| M2 × 12 mm 沉头 | ~6 | 电机安装座 |
| M2 × 14 mm 沉头 | ~4 | 轴承盖 |
| M2 × 18 mm 沉头 | ~4 | 头/尾支撑贯通螺栓 |
| M2 防松螺母 | ~22 | 所有 M2 螺丝 |
| M3 防松螺母 | ~4 | 框架主要节点 |

### 3.4 装配顺序

#### 3.4.1 框架子装配
1. 将轴承装入 `center_bearing_cap` 和 `head_bearing_cover`
2. 用 M2 × 10 mm 螺丝将 `head_support` 安装到 `central_support`
3. 用 M2 × 10 mm 螺丝将 `tail_bracket` 安装到 `central_support`
4. 安装 `lead_screw` 及轴承和端盖
5. 安装 `head_drive_shaft`
6. 将 `head_pin` 和 `tail_pin` 插入枢轴座

#### 3.4.2 电机安装
1. 将三个空心杯电机安装到 `central_support` 的电机座上（M2 × 12 mm）
2. 将 `2-to-3_coupling` 连接到每个电机轴
3. 验证电机轴可手动自由旋转

#### 3.4.3 连杆装配（每翅膀段落）
1. 将 `rod_a`（曲柄）安装至电机输出轴 → 紧定螺钉固定
2. 用铰链销将 `rod_bc`（连杆）连接到 `rod_a`
3. 将 `rod_d`（摇杆）连接到 `rod_bc` 和翅膀枢轴销
4. 安装 `rod_h`、`rod_ij`、`rod_kf` 构成剪式连杆
5. **每侧三个段落均重复上述步骤**
6. **另一侧翅膀镜像装配**

#### 3.4.4 PCB 安装
1. 将 PCB 放置在 `central_support` 的安装柱上
2. 用 M2 螺丝固定（不要拧太紧——FR-4 可能开裂）
3. 将电机线接入 XH-2A 连接器
4. 使用扎带或小型胶粘线夹进行线材管理

#### 3.4.5 电池安装
1. 将锂电池安装在 `central_support` 底面
2. 使用双面泡沫胶 + 魔术贴绑带
3. 将电池连接到 PCB 输入端

---

## 步骤4：最终集成测试

### 4.1 飞前检查
- [ ] 所有螺丝已拧紧（但未滑丝）
- [ ] 所有连杆在全行程范围内自由活动
- [ ] 无线材与运动部件干涉
- [ ] 电池已固定并连接
- [ ] PCB 安装牢固
- [ ] 所有 XH-2A 连接器完全插入

### 4.2 上电流程
1. 将机器人放在软表面上（泡沫垫或毛巾）
2. 拨动 SW2 至 ON
3. LED1 应点亮
4. 翅膀应在约 1 秒内开始扑动
5. 每侧翅膀三个段落应以协调波状运动

### 4.3 调校
- **翅膀1（前缘段）速度** — 调节 R4 微调电位器
- **翅膀2（中段）速度** — 调节 R10 微调电位器
- **翅膀3（后缘段）速度** — 调节 R11 微调电位器
- **理想模式**：前缘略微领先，后缘跟随——形成蝙蝠特有的"波浪"运动

### 4.4 常见问题

| 症状 | 可能原因 | 解决方法 |
|---|---|---|
| 某个电机不转 | L293D 或 XH-2A 虚焊 | 重新回流焊点 |
| 电机仅单向转动 | 74HC04 通道未反相 | 检查 74HC04 输入连接 |
| 翅膀中途卡滞 | 连杆干涉 | 调整连杆长度或间隙 |
| 扑动过快/过慢 | RC 时序偏离 | 调节微调电位器 |
| 电源指示灯不亮 | 电池耗尽或反接 | 检查电池、检查 D1 |
| 噪音过大 | 螺丝松动或轴承缺油 | 拧紧螺丝、润滑轴承 |

---

## 步骤5：维护保养

- **轴承**：每运行约 10 小时加一滴轻质机油
- **连杆关节**：每运行约 5 小时检查磨损；如果出现间隙则更换连杆
- **PCB**：如助焊剂残留吸附灰尘，用异丙醇清洗
- **电池**：不使用时保持 3.7–3.8 V 存储电压
- **电机**：电刷寿命有限；预计连续运行约 50–100 小时需更换

---

**飞行愉快！** 🦇

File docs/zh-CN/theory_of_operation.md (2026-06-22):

# 工作原理 — Hsiwu 电子系统

## 概述

Hsiwu 控制系统采用纯模拟与数字逻辑元件（无微控制器、无固件、无可编程逻辑），产生三路独立同步的往复电机驱动信号。

## 系统框图

```
                   +-----------+
  3.7V 锂电池 ────│ 电源管理   │──── 7.35V ────────────── 电机轨（L293D VCC2）
                   │           │
                   │           │──── 5.0V ───┬────────── 逻辑轨（NE555, 74HC04, L293D VCC1）
                   +-----------+             │
                                             │
              ┌──────────────────────────────┤
              │                              │
       ┌──────┴──────┐               ┌──────┴──────┐
       │ NE555 (U1)  │               │ NE555 (U2)  │  ...
       │ 多谐振荡模式  │               │ 多谐振荡模式  │
       │ ~4.8 Hz     │               │ ~4.8 Hz     │
       └──────┬──────┘               └──────┬──────┘
              │ OUT1                        │ OUT2
       ┌──────┴──────────────────────┐     │
       │       74HC04 (U5)           │     │
       │  ┌─ 非门 ─ /OUT1            │     │
       │  ├─ 非门 ─ /OUT2            │◄────┘
       │  └─ 非门 ─ /OUT3            │
       └──────┬──────────────────────┘
              │
    ┌─────────┼─────────┐
    │   OUT1  │  /OUT1  │
    ▼         ▼         ▼
  ┌──────────────┐
  │ L293D (U6)   │──── 电机1（前缘段）
  │ 半桥驱动      │
  └──────────────┘
  （U7/电机2/中段、U8/电机3/后缘段同理）
```

## 第一级：电源供应

### 输入保护
- **D1**（肖特基二极管，SMC封装） — 防反接保护。电池反接时D1阻断电流。
- **SW2**（SS12D07VG4滑动开关） — 总电源开关。
- **LED1**（绿色0805 LED） — 电源指示，串联限流电阻。

### 升压转换器（MT3608，U4）
MT3608 为定频（1.2 MHz）电流模式升压转换器。

- **输入**：3.7 V（单节锂电池，标称值）
- **输出**：7.35 V（由反馈电阻分压器设定）
- **电感**（L1）：SMD屏蔽功率电感，7.3×6.8 mm
- **输入电容**：10 µF（C1，0805 X7R或X5R）
- **输出电容**：22 µF（C3，SMD铝电解等效）

输出电压由下式给出：
```
V_OUT = V_REF × (1 + R1/R2)
```
其中 V_REF ≈ 0.6 V（MT3608内部基准），R1、R2构成反馈分压网络。

### LDO 稳压器
- 线性稳压器将 7.35 V 升压输出降至干净的 5.0 V，供逻辑 IC（NE555、74HC04）和 L293D 逻辑电源（VCC1）使用。
- 去耦电容（C2、C4）靠近 IC 电源引脚放置。

## 第二级：时序发生（NE555 多谐振荡器）

每片 NE555（U1、U2、U3）配置为**多谐振荡模式**。
在此模式下，输出在 HIGH（≈ VCC）与 LOW（≈ 0 V）之间持续振荡，无需外部触发。

### 电路配置

```
           VCC
            │
           ─┼─ R_A ──┬── R_B ──┬── VCC
            │        │         │
            │        ├── 引脚7（DISCH）
            │        │
            ├────────┼── 引脚6,2（THRES, TRIG）
            │        │
            │       ─┼─ C
            │        │
           ─┴────────┴── GND
```

### 时序方程

**输出高电平时间（t_H）：**
```
t_H = 0.693 × (R_A + R_B) × C
```

**输出低电平时间（t_L）：**
```
t_L = 0.693 × R_B × C
```

**周期：**
```
T = t_H + t_L = 0.693 × (R_A + 2·R_B) × C
```

**频率：**
```
f = 1/T = 1.44 / ((R_A + 2·R_B) × C)
```

### 设计参数（~4.8 Hz）

| 参数 | 数值 | 备注 |
|---|---|---|
| R_A | ~10 kΩ（固定+微调） | U1为 R + R4（微调） |
| R_B | ~100 kΩ | 固定 0805 电阻 |
| C | ~1 µF | 陶瓷或钽电容 |
| **目标频率 f** | ~4.8 Hz | 参考设计10 Hz按比例降低 |
| **目标周期 T** | ~208 ms | |
| **占空比** | ~52% | 设计上略有不对称 |

**频率微调：** 每路 NE555 有一个可调电阻（U1为R4，U2为R10，U3为R11）——三端 SMD 微调电位器。调节这些可改变 R_A，从而改变振荡频率，实现各段时序独立校准。

### 启动同步

三片 NE555 共享同一 VCC 轨，RC 网络相近，上电时趋向于近似同步启动。但由于元件公差，会逐渐漂移。无论相对相位如何，74HC04 级确保每个电机始终获得互补驱动信号。

## 第三级：相位反相（74HC04）

74HC04 为六反相器（六个独立非门）。仅使用三个：

| 门 | 输入 | 输出 | 用途 |
|---|---|---|---|
| 1A → 1Y | NE555 U1 OUT | /OUT1 | L293D U6 反向驱动 |
| 2A → 2Y | NE555 U2 OUT | /OUT2 | L293D U7 反向驱动 |
| 3A → 3Y | NE555 U3 OUT | /OUT3 | L293D U8 反向驱动 |

每路 NE555 输出同时连接至对应 L293D 输入引脚**和**一个 74HC04 输入。反相输出连接至互补 L293D 输入引脚。

### 信号关系

```
NE555 OUT = HIGH → L293D IN1 = HIGH, IN2 = LOW  → 电机正转
NE555 OUT = LOW  → L293D IN1 = LOW,  IN2 = HIGH → 电机反转
```

以此实现连续正反转往复运动。

### 未使用的门

三路未使用的反相器（4A/4Y、5A/5Y、6A/6Y）的输入端应接 GND，防止浮空输入振荡和额外电流消耗。

## 第四级：电机驱动（L293D）

L293D 为双 H 桥驱动芯片，每通道可提供 600 mA（峰值 1.2 A）。

### 引脚配置（每电机，使用一个半桥）

| L293D 引脚 | 连接 | 用途 |
|---|---|---|
| VCC1（引脚16） | 5 V 轨 | 逻辑供电 |
| VCC2（引脚8） | 7.35 V 轨 | 电机供电 |
| 1,2EN（引脚1） | 5 V（常使能） | 半桥1-2使能 |
| 1A（引脚2） | NE555 OUT | 输入A — 方向控制 |
| 2A（引脚7） | 74HC04 /OUT | 输入B — 互补方向 |
| 1Y（引脚3） | 电机端子+ | 电机输出 |
| 2Y（引脚6） | 电机端子− | 电机输出 |
| GND（引脚4,5,12,13） | 公共地 | 功率+逻辑回流 |

### 真值表

| 1A (IN1) | 2A (IN2) | 电机 |
|---|---|---|
| H | L | 正转（电机两端+7.35 V） |
| L | H | 反转（电机两端−7.35 V） |
| L | L | 制动（电机两端短接至GND） |
| H | H | 制动（电机两端短接至VCC2） |

正常工作时，1A 和 2A 始终互补，电机始终处于正转或反转驱动状态——不会制动。制动状态仅在逻辑切换的几纳秒过渡期间出现。

### 内置保护

L293D 内含：
- **续流二极管**位于所有输出端——无需外加二极管
- **热关断**——防止过热
- **过流限制**——内部限流

## 系统级时序

一个翅膀段落的完整信号链：

```
t = 0:    NE555 OUT 变 HIGH
          → L293D IN1 = HIGH, IN2 = LOW
          → 电机正转
          → 翅膀段落上扑

t = t_H:  NE555 OUT 变 LOW（约108 ms后，~52%占空比）
          → L293D IN1 = LOW, IN2 = HIGH
          → 电机反转
          → 翅膀段落下扑（回程）

t = T:    NE555 OUT 再次变 HIGH（约208 ms总计）
          → 循环以 ~4.8 Hz 重复
```

## 设计理由

### 为什么选用 NE555？

- **简洁** — 三个外部元件（R_A、R_B、C）即可设定频率
- **宽供电范围** — 4.5 V 至 16 V，兼容 5 V 逻辑轨
- **驱动能力充足** — 可输出/吸入 200 mA，足以驱动 74HC04 输入和 L293D 逻辑输入
- **久经考验** — NE555 是史上文档最完备的 IC 之一

### 为什么选用 74HC04，而非直接从 NE555 取互补输出？

NE555 输出级为图腾柱（推挽）结构——仅提供单一输出。互补输出需外部晶体管反相器或逻辑门。74HC04 单颗芯片提供六个反相器，三路 NE555 通道仅用三个——简洁紧凑。

### 为什么是 ~4.8 Hz（而非参考文献的 ~10 Hz）？

参考样机（齐津浩、张卫平，2020）实现约 10 Hz 扑动频率。Hsiwu 设计目标为约 4.8 Hz——约为一半频率——原因如下：

1. **更大单次扑动幅度** — 较低频率使翅膀在空气阻尼截止前达到完整 70° 行程
2. **降低机械应力** — 3D 打印连杆和框架承受更低循环载荷
3. **可观察性** — 在 4.8 Hz 下，分段翼膜变形肉眼清晰可辨
4. **电机电流余量** — 较低频率意味单节锂电池平均电流消耗更低

通过调节三路微调电位器（R4、R10、R11）减小 R_A，可在系统机械极限范围内提高频率。

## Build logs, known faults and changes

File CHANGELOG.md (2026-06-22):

# Changelog

All notable changes to the Hsiwu project are documented in this file.

The format is based on [Keep a Changelog](https://keepachangelog.com/en/1.1.0/),
and this project adheres to [Semantic Versioning](https://semver.org/spec/v2.0.0.html).

---

## [1.0.0] — 2025-06-20

### Added

#### Electronics
- Complete system schematic: three NE555 astable multivibrator stages (~4.8 Hz
  square-wave output) → 74HC04 hex inverter for complementary phase generation
  → three L293D dual H-bridge motor drivers, each using one half-bridge channel
  per motor to produce continuous forward/reverse reciprocation.
- Power management block: MT3608 boost converter (3.7 V → 7.35 V for motors),
  on-board LDO (5 V for logic), Schottky diode reverse-polarity protection,
  slide power switch (SS12D07VG4) with green indicator LED.
- Custom irregularly-shaped PCB designed in EasyEDA (LCEDA project in
  `electronics/source/JLC/`) and re-captured in Altium Designer (`.schdoc` /
  `.pcbdoc` in `electronics/source/Altium Designer/`). PCB contour follows the
  internal mechanical frame curvature.
- Full Gerber manufacturing files (`electronics/output/gerber/`), pick-and-place
  data (`electronics/output/pick_and_place/`), and BOM export
  (`electronics/output/bom/`).

#### Mechanical
- Parametric 3D model of the full robot assembly in SolidWorks (`final_assembly.SLDASM`).
- Six linkage rod types (`rod_a`, `rod_bc`, `rod_d`, `rod_h`, `rod_ij`, `rod_kf`)
  forming the crank-rocker four-bar kinematic chains for each wing segment.
- Structural frame sub-assembly: central support, head support, tail bracket,
  lead screw, bearings, bearing caps, hinge pins.
- Motor & coupling sub-assembly: hollow-cup DC motor (4-stage planetary geared)
  and 2-to-3 shaft coupler.
- Fastener models: M2 countersunk screws (10/12/14/18 mm) and M2/M3 lock nuts.
- Full 3D PCB assembly with all electronic components placed for mechanical fit checking.
- Export files: STEP for 3D-printing (`mechanical/output/3dp/`), STL for laser
  cutting (`mechanical/output/laser/`).

#### Documentation
- `README.md` — full project overview in English, including system architecture,
  design specifications, replication guide, and visual assets.
- `README.zh-CN.md` — complete Chinese-language counterpart.
- Reference paper included (`media/photos/reference/仿生蝙蝠飞行器的设计制造_齐津浩.pdf`).

#### Media
- 3D renders: full assembly color render, front elevation, top view, isometric wireframe.
- PCB views: 3D render, 2D top/bottom layers, raw copper routing.
- Lead screw scissor mechanism animation (`screw_movement.gif`).
- Test & measurement photographs: assembly setup, soldering, oscilloscope test.

#### Repository Setup
- `.gitignore` — comprehensive rules for CAD/EDA/3D-printing project.
- `.gitattributes` — binary/text handling and diff configuration.
- `CONTRIBUTING.md` — contributor guidelines.
- `LICENSE.md` — MIT License.
- `.github/` — pull request template, issue templates, CODEOWNERS.

---

## Versioning Conventions

- **Major (X.0.0)**: Breaking changes to the physical design (mechanical
  dimensions, PCB form factor, connector pinout) that make it incompatible with
  previously manufactured parts.
- **Minor (0.X.0)**: New sub-assemblies, additional documentation, significant
  performance tuning, or new export formats.
- **Patch (0.0.X)**: Typo fixes, documentation corrections, minor BOM updates,
  image replacements.

---

[1.0.0]: https://github.com/Robusr/Hsiwu/releases/tag/v1.0.0

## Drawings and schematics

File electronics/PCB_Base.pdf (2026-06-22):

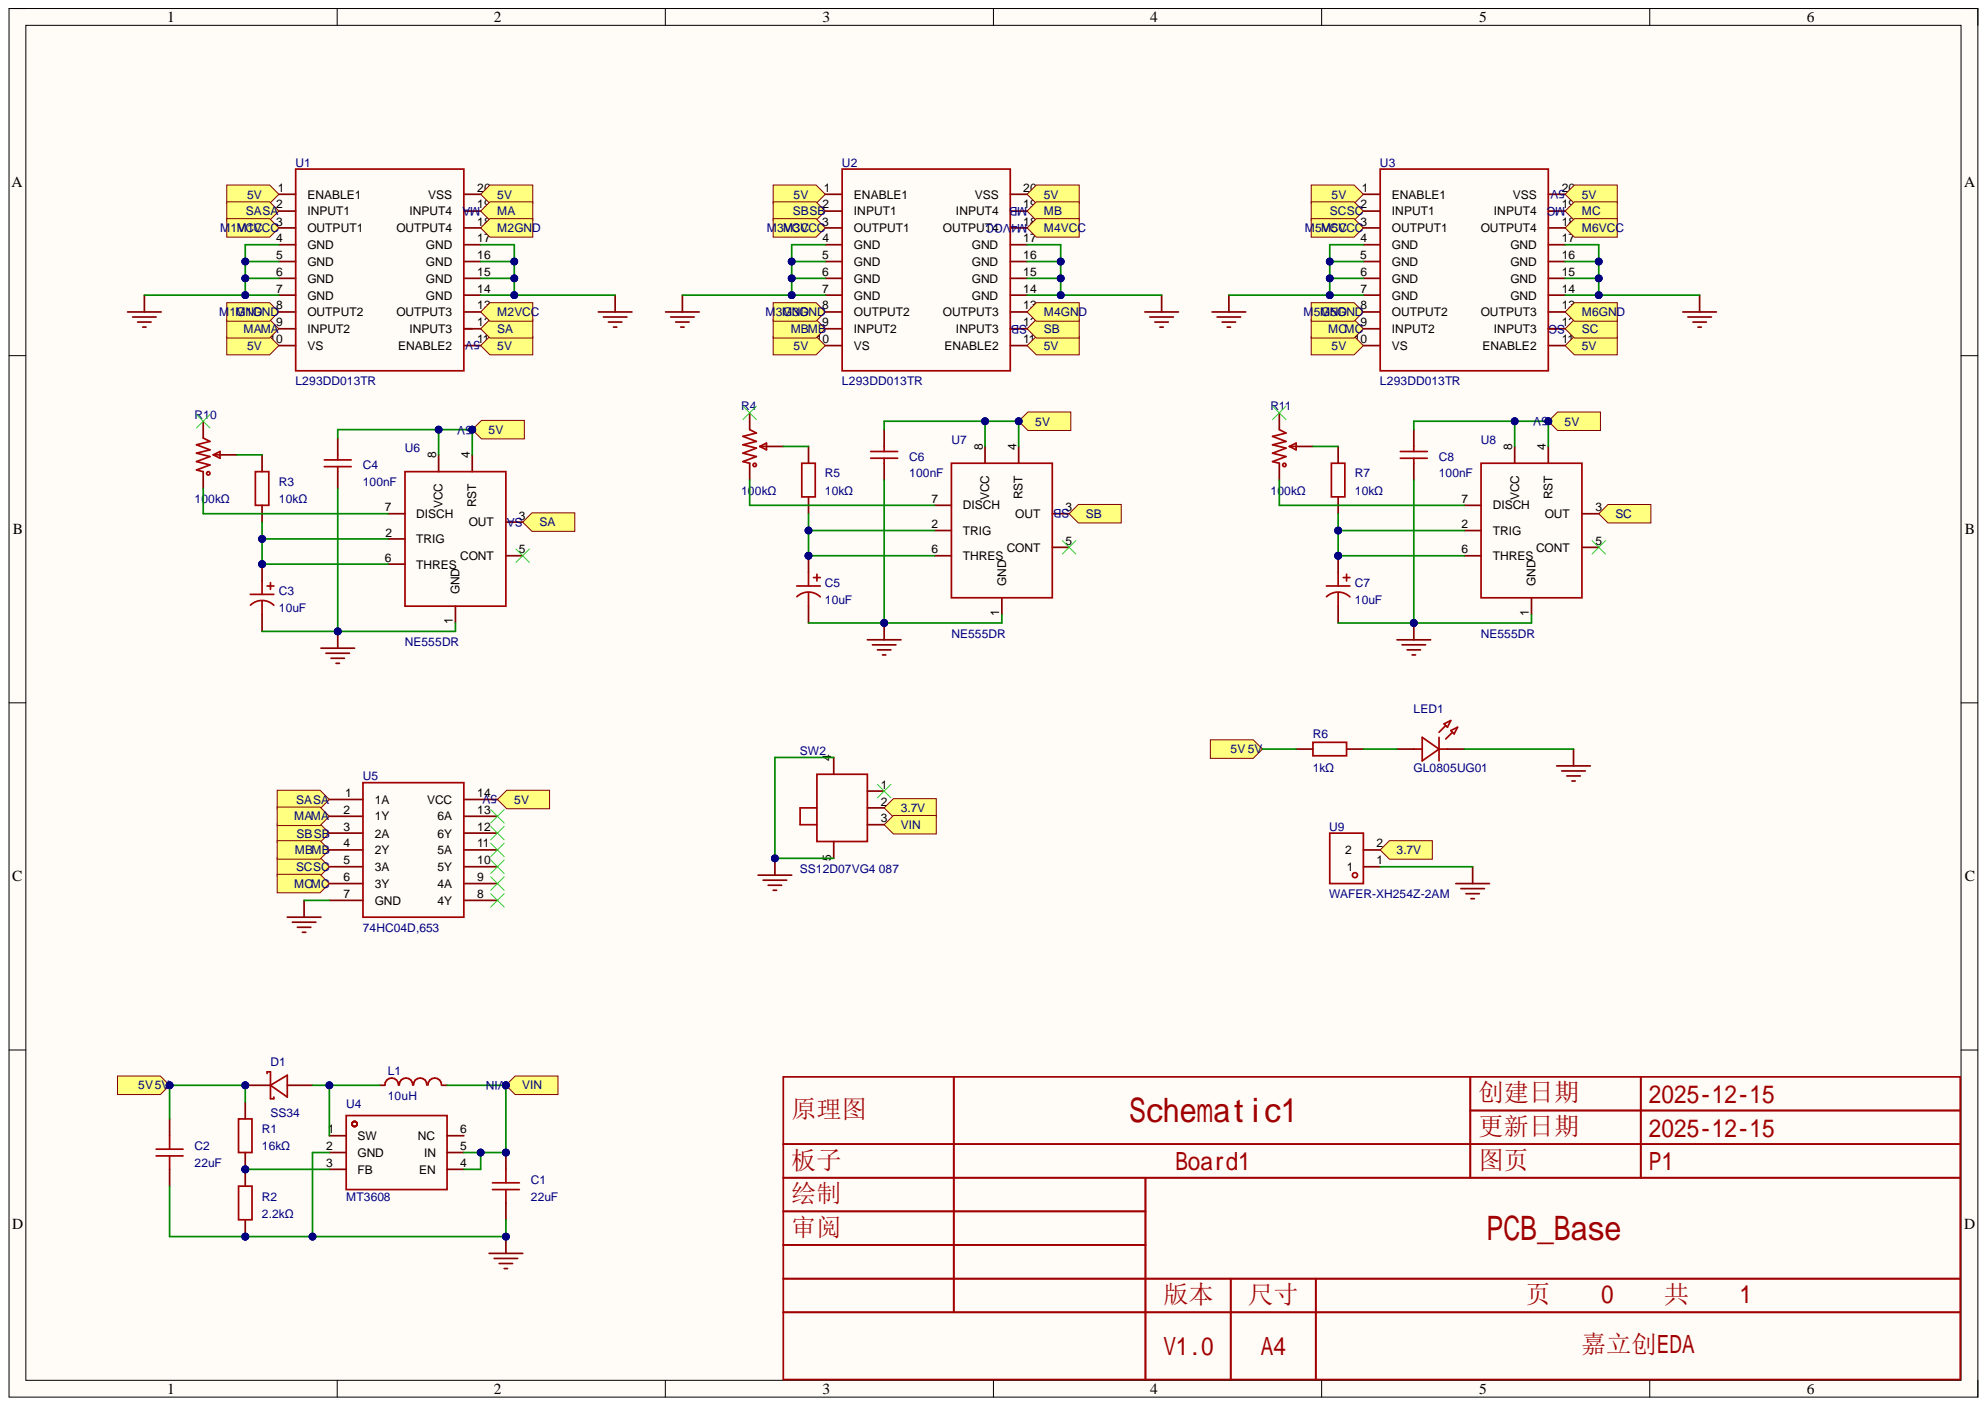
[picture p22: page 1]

原理图 | Schematic1 | 创建日期 | 2025-12-15

板子 | Board1 | 图页 | P1
绘制 | | PCB_Base
审阅

V1.0 | A4 | 嘉立创EDA

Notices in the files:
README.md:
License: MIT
